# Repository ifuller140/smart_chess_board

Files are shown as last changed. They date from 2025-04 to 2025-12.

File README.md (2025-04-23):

# SmartChessBoard
Software Repository For Smart Chess Board Project

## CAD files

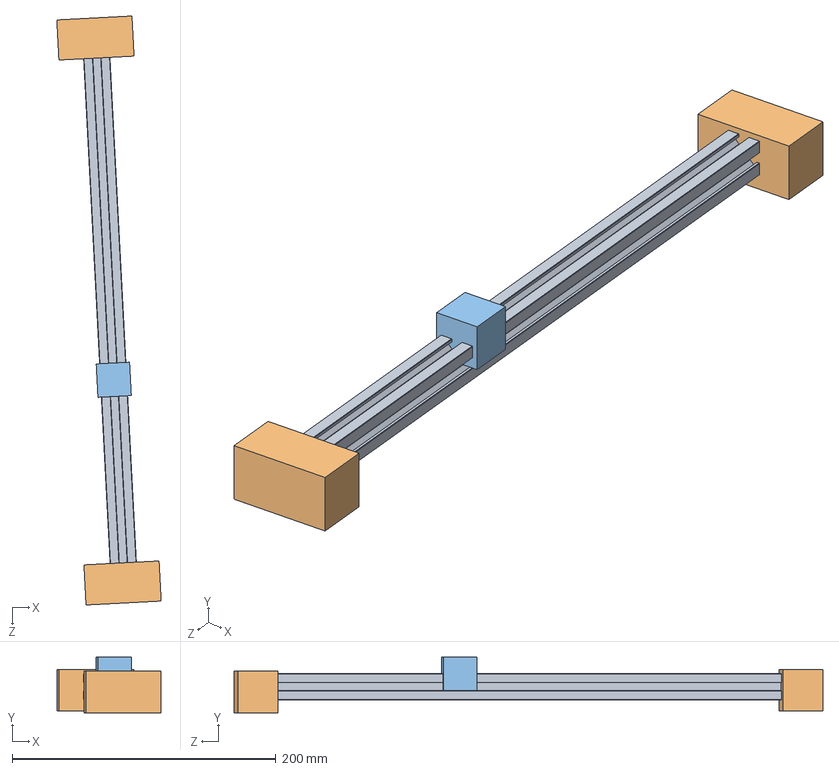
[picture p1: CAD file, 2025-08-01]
simulation/cad/exported files/Robot_Assembly.STEP
79.2 x 42.2 x 446.9 mm
Gantry_Bracket x 2
Gantry_Servo

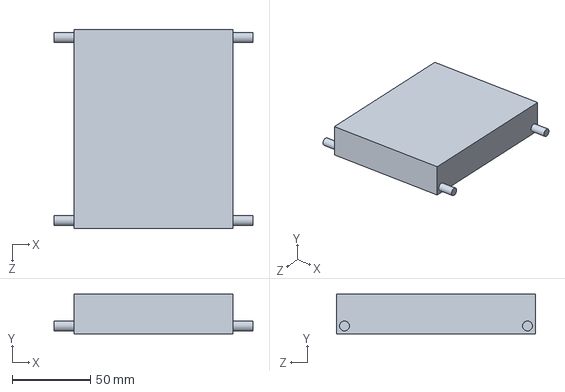
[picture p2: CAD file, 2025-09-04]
simulation/cad/Test/Main Frame.SLDPRT
127.0 x 25.4 x 127.0 mm

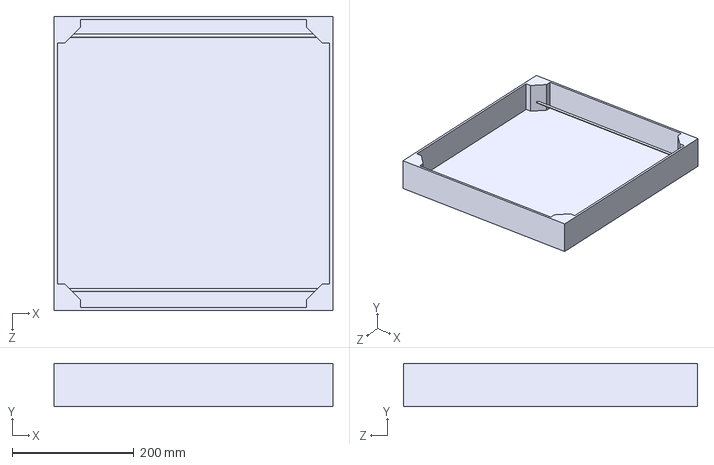
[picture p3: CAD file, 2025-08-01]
simulation/cad/exported files/Base_Assembly.STEP
457.2 x 71.1 x 482.6 mm

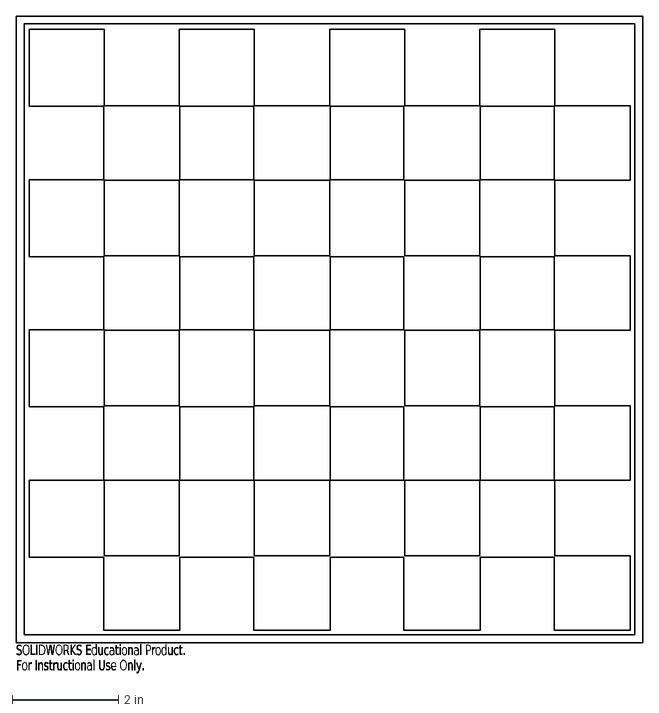
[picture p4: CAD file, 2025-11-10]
cad/exports/DXF/chess1.DXF
SOLIDWORKS Educational Product.
For Instructional Use Only.

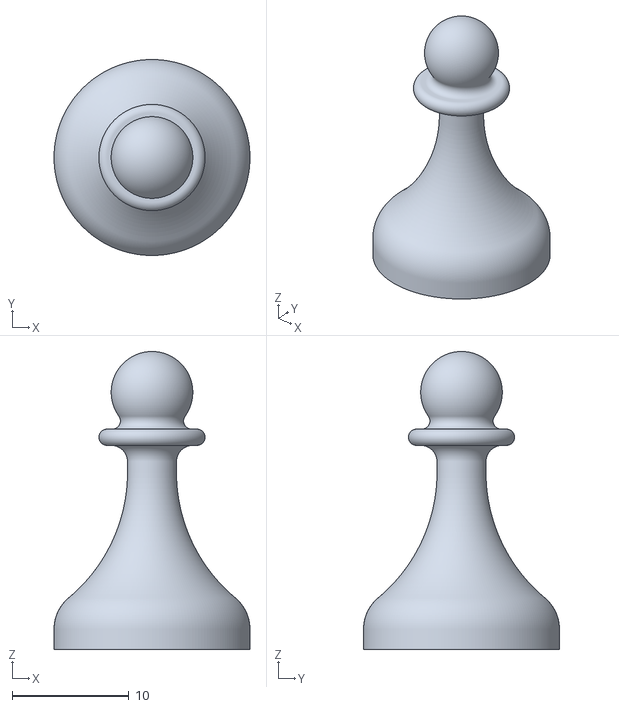
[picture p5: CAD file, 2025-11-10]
cad/exports/STLs/pawn.STL
16.8 x 16.8 x 25.5

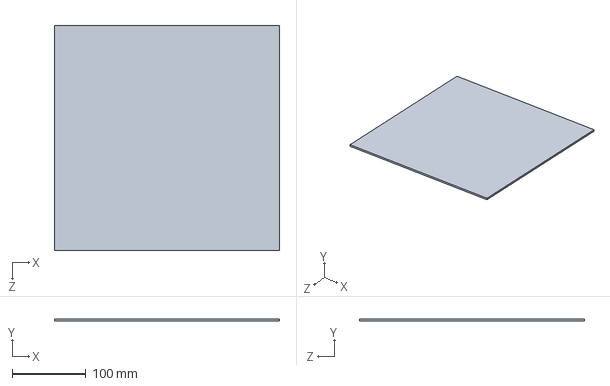
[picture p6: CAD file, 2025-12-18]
cad/parts/Chess Board.SLDPRT
304.8 x 3.17 x 304.8 mm

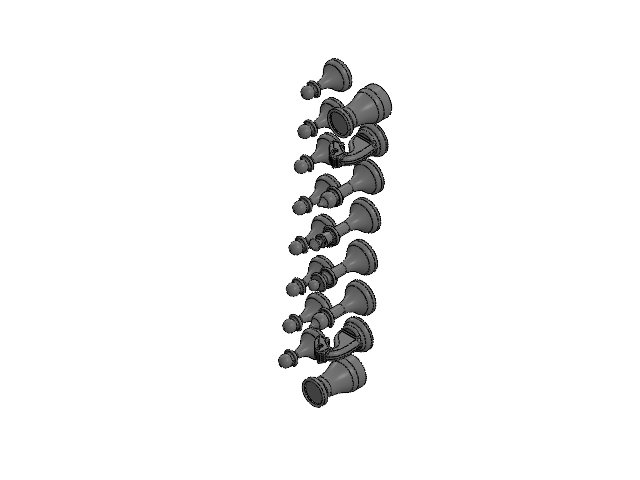
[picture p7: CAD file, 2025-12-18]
cad/parts/chess pieces/chess_pieces_assembly.SLDASM
bishop x 2
horse x 2
king
kings_crown
pawn x 8
queen
queens_crown
rook x 2

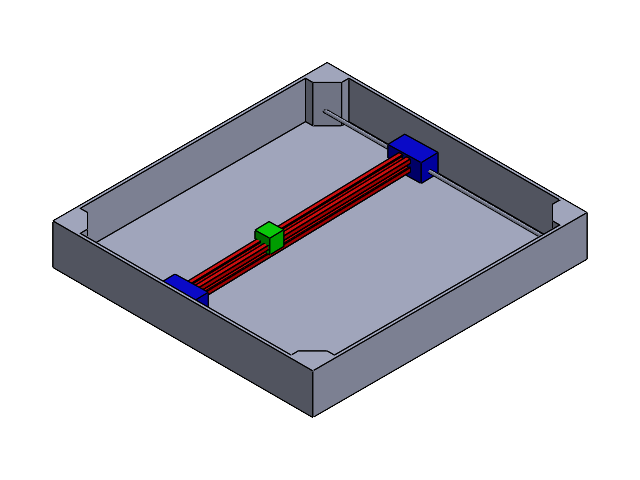
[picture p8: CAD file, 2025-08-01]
simulation/cad/assemblies/Full_Assembly.SLDASM
Gantry_Bracket x 2
Gantry_Servo
base

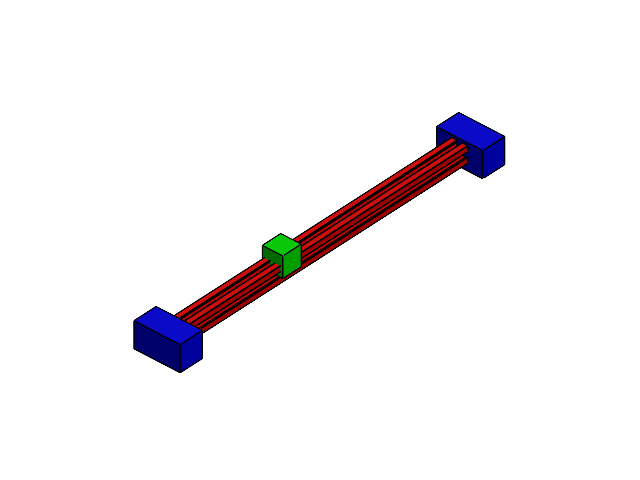
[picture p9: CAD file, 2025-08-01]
simulation/cad/assemblies/Robot_Assembly.SLDASM
Gantry_Bracket x 2
Gantry_Servo

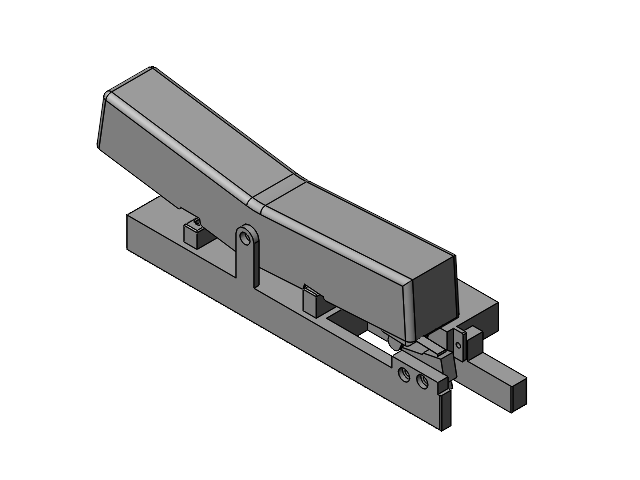
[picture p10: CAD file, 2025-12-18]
cad/parts/Inner Clock Subassembly.SLDASM
Servo base
servo rotator
Clock toy
Clock toy bottom
mini limit switch

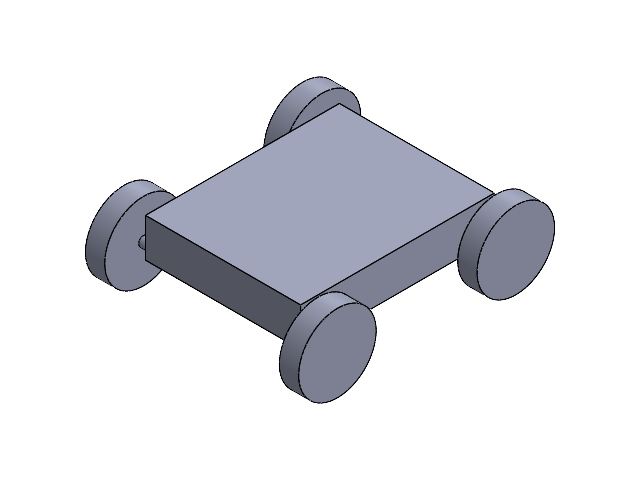
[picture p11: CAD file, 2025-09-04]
simulation/cad/Test/Assem1.SLDASM
Main Frame
Wheel x 4

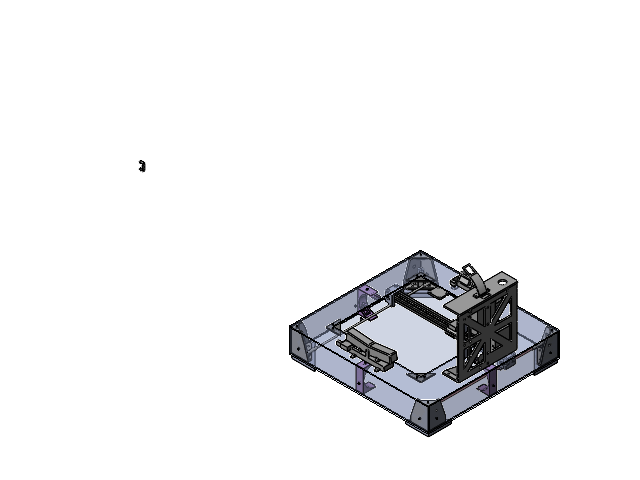
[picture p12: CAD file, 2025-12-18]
cad/parts/Assembly V2.SLDASM
Bottom V1
Side 19in x 2
Side 18in x 2
Vertical rod V1 x 2
bottom-side-top connector x 4
Top
Triangle piece holder x 4
Servo base x 2
servo rotator x 2
Clock toy
Clock toy bottom
mini limit switch x 3
clock face x 2
clock face holder
Battery
Raspberry Pi
Motor controller
Electronics peg board v2
Electronics top v2
Camera holder
Power Splitter x 2
Corner SW 1 x 2
Corner SW 2 motor
Stepper motor x 2
Rail rider
Servo magnet holder
feet V3 x 4
Tbone
Gates_2GT_20T_Toothed_Pulley x 4
Gates_2GT_20T_Toothed_Idler x 4
Corner SW 2 motor controller
Tbone clip
Wire holders under clcok housing x 2
Tbone without limit switches

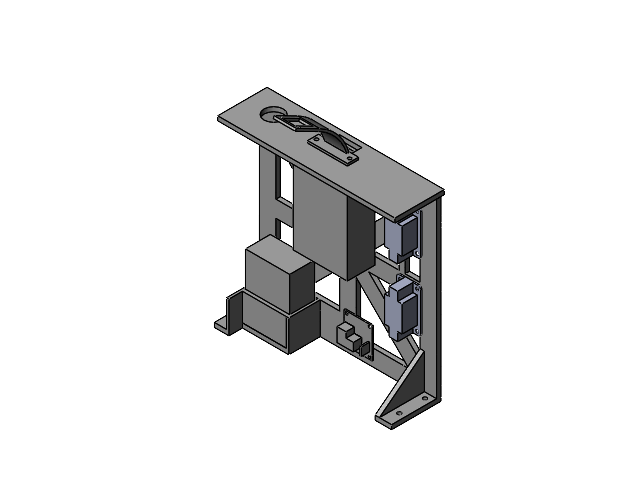
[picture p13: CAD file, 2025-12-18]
cad/parts/Electronics Assembly.SLDASM
Battery
Raspberry Pi
Motor controller
Electronics peg board v2
Electronics top v2
Camera holder
Power Splitter x 2

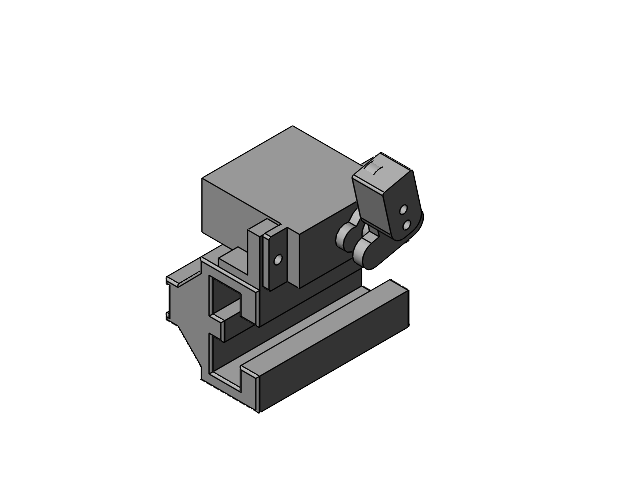
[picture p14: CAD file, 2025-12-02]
cad/parts/magent piece.SLDASM
Rail rider
Servo base
servo rotator
Servo magnet holder

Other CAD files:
simulation/cad/assemblies/Base_Assembly.SLDASM
cad/versions/Out of date/Assembly V1.SLDASM
cad/parts/Clock subassembly.SLDASM
cad/parts/Tbone assembly.SLDASM
cad/exports/Engineering drawings/Bottom V1.SLDDRW
cad/exports/Engineering drawings/Side 18in.SLDDRW
cad/exports/Engineering drawings/Side 19in.SLDDRW
cad/exports/Engineering drawings/Top.SLDDRW
cad/exports/STLs/Camera holder.STL
cad/exports/STLs/Clock toy bottom.STL
cad/exports/STLs/Clock toy.STL
cad/exports/STLs/Corner SW 1.STL
cad/exports/STLs/Corner SW 2 motor controller.STL
cad/exports/STLs/Corner SW 2 motor.STL
cad/exports/STLs/Corner2v2.stl
cad/exports/STLs/Corner2v3.stl
cad/exports/STLs/Electronics peg board v2.STL
cad/exports/STLs/Electronics peg board.STL
cad/exports/STLs/Electronics top v2.STL
cad/exports/STLs/Electronics top.STL
cad/exports/STLs/Feet.stl
cad/exports/STLs/Rail rider.STL
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

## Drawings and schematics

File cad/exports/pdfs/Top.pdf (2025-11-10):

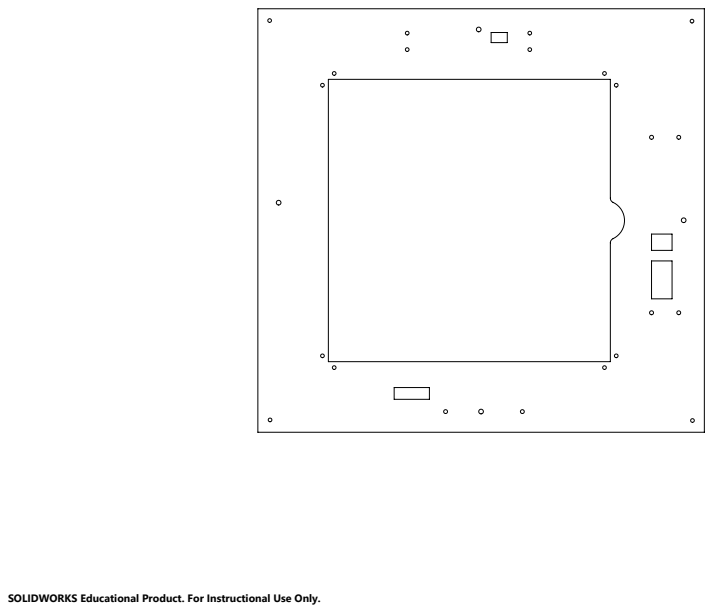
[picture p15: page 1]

SOLIDWORKS Educational Product. For Instructional Use Only.

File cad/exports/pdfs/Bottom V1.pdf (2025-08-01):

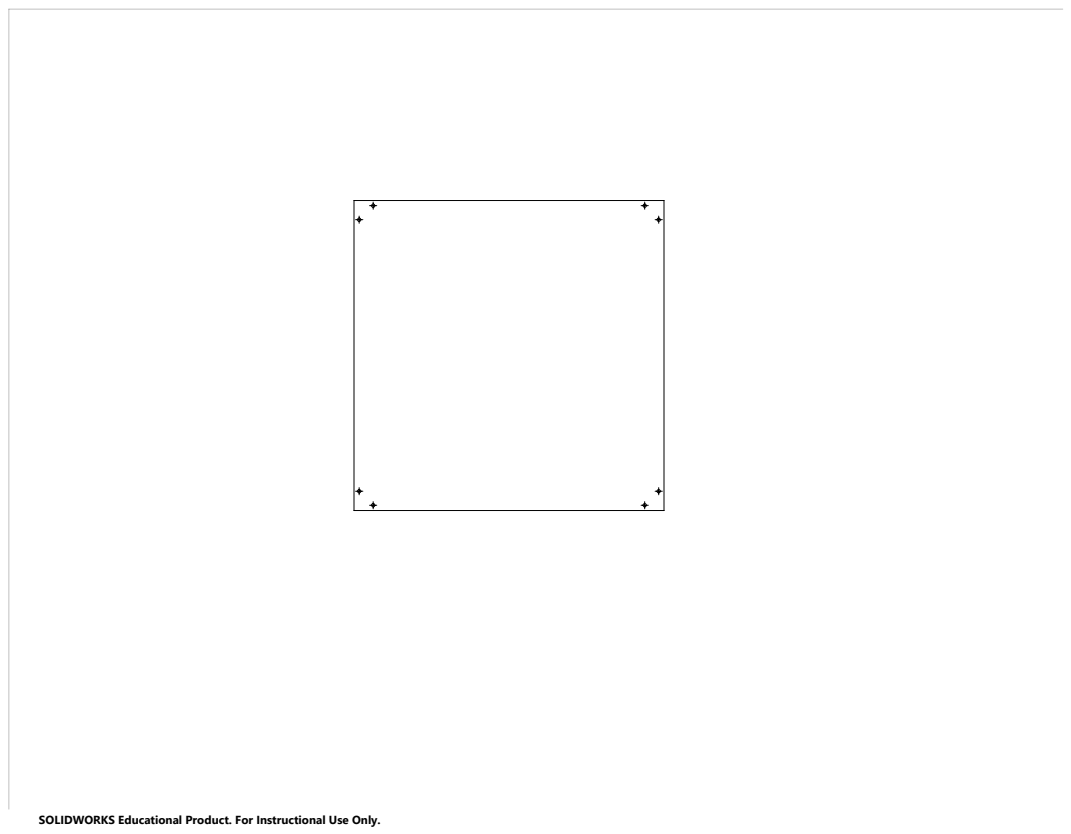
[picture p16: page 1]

SOLIDWORKS Educational Product. For Instructional Use Only.

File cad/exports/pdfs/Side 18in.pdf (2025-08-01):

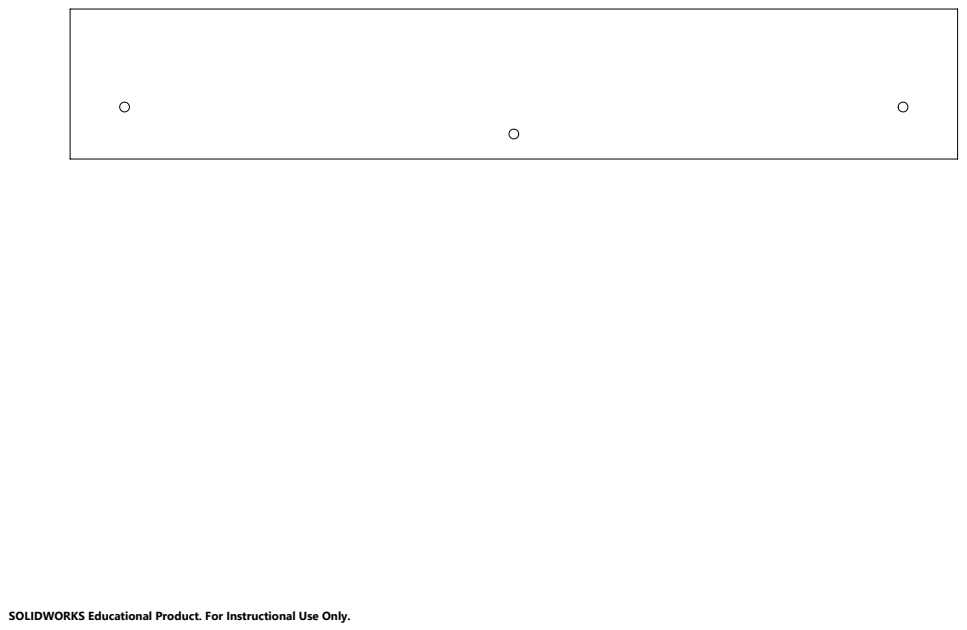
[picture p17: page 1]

SOLIDWORKS Educational Product. For Instructional Use Only.

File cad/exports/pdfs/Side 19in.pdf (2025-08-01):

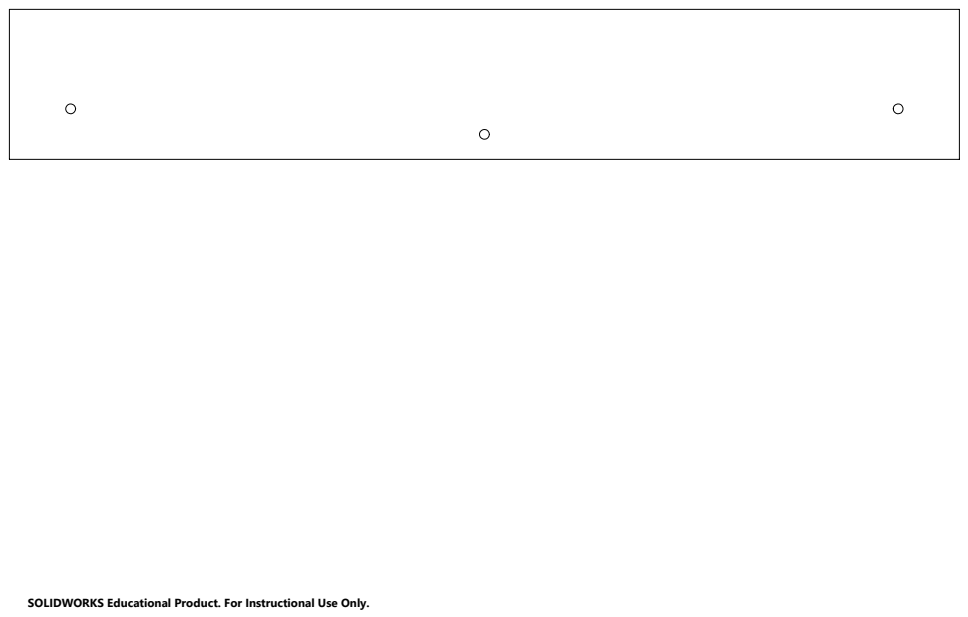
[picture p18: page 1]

SOLIDWORKS Educational Product. For Instructional Use Only.

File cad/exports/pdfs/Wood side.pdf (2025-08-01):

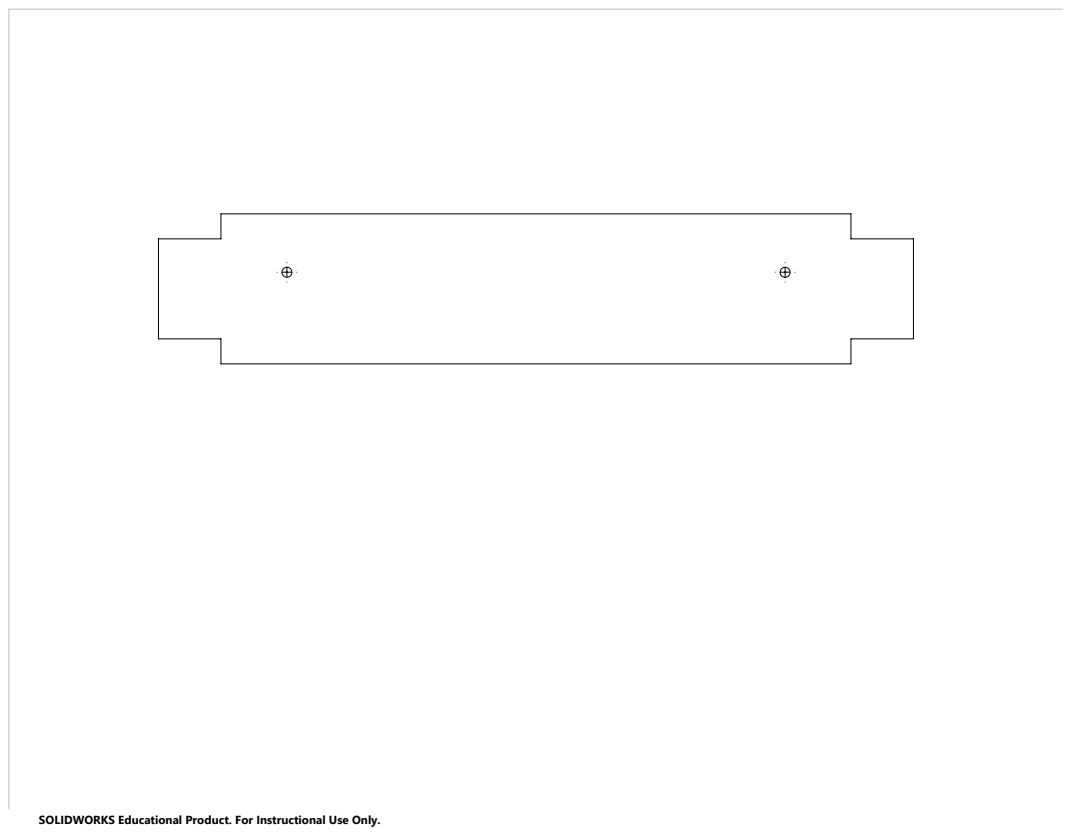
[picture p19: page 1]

SOLIDWORKS Educational Product. For Instructional Use Only.

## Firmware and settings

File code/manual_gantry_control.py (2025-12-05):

#!/usr/bin/env python3
import RPi.GPIO as GPIO
import time
import keyboard  # pip install keyboard

# ==========================
# GPIO PIN DEFINITIONS
# ==========================
# Motor A
IN1_A = 2
IN2_A = 3
IN3_A = 4
IN4_A = 14

# Motor B
IN1_B = 24
IN2_B = 23
IN3_B = 22
IN4_B = 27

# Define GPIO pins in arrays
motorA_pins = [IN1_A, IN2_A, IN3_A, IN4_A]
motorB_pins = [IN1_B, IN2_B, IN3_B, IN4_B]

# ==========================
# STEPPER SEQUENCE (28BYJ-48)
# ==========================
seq = [
    [1,1,0,0],
    [0,1,1,0],
    [0,0,1,1],
    [1,0,0,1]
]

# ==========================
# GPIO SETUP
# ==========================
GPIO.setmode(GPIO.BCM)
for pin in motorA_pins + motorB_pins:
    GPIO.setup(pin, GPIO.OUT)
    GPIO.output(pin, 0)

# ==========================
# STEPPER CONTROL FUNCTIONS
# ==========================
def step_motor(pins, direction=1, delay=0.002):
    """Step a single motor one cycle in the given direction."""
    seq_len = len(seq)
    for step in range(seq_len):
        for pin in range(4):
            GPIO.output(pins[pin], seq[step][pin] if direction > 0 else seq[-step - 1][pin])
        time.sleep(delay)

def move_both(dirA, dirB, steps, delay=0.002):
    """Move both motors simultaneously."""
    for _ in range(steps):
        step_motor(motorA_pins, dirA, delay)
        step_motor(motorB_pins, dirB, delay)

# ==========================
# COREXY MOVEMENT FUNCTIONS
# ==========================
def move_x(steps, delay=0.002):
    """Move X-axis: both motors same direction."""
    direction = 1 if steps > 0 else -1
    move_both(direction, direction, abs(steps), delay)

def move_y(steps, delay=0.002):
    """Move Y-axis: motors opposite directions."""
    direction = 1 if steps > 0 else -1
    move_both(direction, -direction, abs(steps), delay)

# ==========================
# MAIN LOOP: KEYBOARD CONTROL
# ==========================
try:
    step_size = 20     # Number of steps per key press
    delay = 0.0015     # Step timing (lower = faster)

    print("Manual Gantry Control Active!")
    print("Use arrow keys to move. Press 'q' to quit.\n")

    while True:
        if keyboard.is_pressed('up'):
            print("Moving UP (Y+)")
            move_y(step_size, delay)

        elif keyboard.is_pressed('down'):
            print("Moving DOWN (Y-)")
            move_y(-step_size, delay)

        elif keyboard.is_pressed('left'):
            print("Moving LEFT (X-)")
            move_x(-step_size, delay)

        elif keyboard.is_pressed('right'):
            print("Moving RIGHT (X+)")
            move_x(step_size, delay)

        elif keyboard.is_pressed('q'):
            print("Exiting program...")
            break

        time.sleep(0.05)

except KeyboardInterrupt:
    print("\nStopped by user.")

finally:
    GPIO.cleanup()
    print("GPIO cleaned up.")

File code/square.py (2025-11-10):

#!/usr/bin/env python3
import RPi.GPIO as GPIO
import time

# ==========================
# GPIO PIN DEFINITIONS
# ==========================
# Motor A
IN1_A = 2
IN2_A = 3
IN3_A = 4
IN4_A = 14

# Motor B
IN1_B = 24
IN2_B = 23
IN3_B = 22
IN4_B = 27

# Define GPIO pins in arrays
motorA_pins = [IN1_A, IN2_A, IN3_A, IN4_A]
motorB_pins = [IN1_B, IN2_B, IN3_B, IN4_B]

# ==========================
# STEPPER SEQUENCE
# ==========================
# Full_step sequence for 28BYJ-48
seq = [
    [1,1,0,0],
    [0,1,1,0],
    [0,0,1,1],
    [1,0,0,1]
]

# ==========================
# GPIO SETUP
# ==========================
GPIO.setmode(GPIO.BCM)
for pin in motorA_pins + motorB_pins:
    GPIO.setup(pin, GPIO.OUT)
    GPIO.output(pin, 0)

# ==========================
# STEPPER MOTOR FUNCTION
# ==========================
def step_motor(pins, direction=1, delay=0.002):
    """Step a single motor one step in the given direction."""
    global seq
    seq_len = len(seq)
    for step in range(seq_len):
        for pin in range(4):
            GPIO.output(pins[pin], seq[step][pin] if direction > 0 else seq[-step - 1][pin])
        time.sleep(delay)

def move_both(dirA, dirB, steps, delay=0.002):
    """Move both motors simultaneously."""
    for _ in range(steps):
        step_motor(motorA_pins, dirA, delay)
        step_motor(motorB_pins, dirB, delay)

# ==========================
# COREXY MOTION FUNCTIONS
# ==========================
def move_x(distance_steps, delay=0.002):
    """Move along X axis (both motors same direction)."""
    move_both(1, 1, distance_steps, delay)

def move_y(distance_steps, delay=0.002):
    """Move along Y axis (motors opposite directions)."""
    move_both(1, -1, distance_steps, delay)

def move_diag_xy(distance_steps, delay=0.002):
    """Move along diagonal bottom-left to top-right (X+Y+)."""
    move_both(1, 0, distance_steps, delay)  # Adjust ratio if needed

def move_diag_yx(distance_steps, delay=0.002):
    """Move along diagonal top-left to bottom-right (X-Y+)."""
    move_both(1, -1, distance_steps, delay)

# ==========================
# MAIN PROGRAM
# ==========================
try:
    steps_per_side = 300  # Adjust for desired size
    delay = 0.002

    print("Starting CoreXY square pattern...")

    # Square movement
    move_x(steps_per_side, delay)
    move_y(steps_per_side, delay)
    move_x(-steps_per_side, delay)
    move_y(-steps_per_side, delay)

    print("Square complete. Drawing X pattern...")

    # X pattern (diagonals)
    move_both(1, -1, steps_per_side, delay)   # diagonal 1
    move_both(-1, 1, steps_per_side, delay)   # diagonal 2

    print("Pattern complete.")

except KeyboardInterrupt:
    print("Interrupted by user.")
finally:
    GPIO.cleanup()

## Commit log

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2025-11-02 fixed broken mates
    [Assembly V2.SLDASM]
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2025-11-03 tbone enlarge tolerances
    [Assembly V2.SLDASM, Tbone assembly.SLDASM, Tbone without limit switches.SLDPRT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]
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2026-02-02 Add interactive stepper motor test with TM1637 display and improve A4988 timing constants for stability.
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2026-02-08 Implement pigpio DMA for jitter-free stepper motor control and update limit switch and button logic to active HIGH.
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2026-02-10 Refactor gantry hardware tests to use ROS nodes for control and fix inverted stepper motor direction logic
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2026-05-01 Fix perception stack: 10 critical bugs, refactor board detector, add auto-reference capture
    P0 fixes (crash/correctness):
    - BUG-06: picamera2 RGB→BGR conversion in camera_node._read_frame()
    - BUG-03: Fix BoardState.corners assignment (build list, don't index fixed array)
    - BUG-01: Calibration format — switch calibration.py save/load from .npz to OpenCV YAML
    - BUG-10: Remove duplicate rclpy.ok() in camera_node and piece_detector_node
    P1 fixes (bad behavior):
    - BUG-05: Fix white-piece brightness formula (was relative*board_mean, now absolute 0-255)
    - BUG-04/12: Fix board_detection.py comments (H/V labels); lower Hough threshold 100→70,
    reduce line requirement 8→4 for reli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
2026-05-01 Fix camera_node for Ubuntu 22.04: add GStreamer fallback, clear libcamera install instructions
    - camera_node: Replace monolithic _init_camera with three separate backends:
    1. picamera2 (preferred) — now logs exact apt install command when libcamera missing
    2. GStreamer libcamerasrc pipeline (Ubuntu 22.04 fallback, works if OpenCV has GStreamer)
    3. OpenCV V4L2 — probes /dev/video0-3, validates frames are non-black before accepting
    - camera_node: Fix 'OpenCV capture read failed' spam — V4L2 fallback now test-reads
    before accepting the device, so if V4L2 cannot produce real frames it logs one clear
    error rather than flooding the console
    - install_libcamera_python.sh: Rewrite w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
2026-05-01 Switch perception launches to use ros-humble-camera-ros for Ubuntu 22.04 Pi
    On Ubuntu 22.04, python3-libcamera is not in standard repos and the RPi
    Foundation repo uses Debian naming (not Ubuntu). ros-humble-camera-ros IS
    available and works: camera detected as imx219, BGR888 format supported.
    Both launch files now default to use_camera_ros:=True which starts
    camera_ros camera_node with format=BGR888 remapped to /camera/image_raw.
    This produces proper bgr8 images so all downstream nodes work correctly.
    Old chess_perception camera_node is kept as fallback with:
    use_camera_ros:=False (+ optional use_picamera2:=True/False)
    New parameters exposed in both launch files:
    use_camera_ros (bool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
2026-05-01 Fix camera_ros topic remap: use fully-qualified path not relative
    camera_ros publishes to /camera_node/image_raw (fully qualified), not
    the relative 'image_raw'. Relative remaps are ignored. Use absolute
    path remap: /camera_node/image_raw -> /camera/image_raw.
2026-05-01 Add detection_scale and skip_frames to board_detector_node to fix CPU overload
    On Pi 4 at 12fps with 1280x720, board_detector_node was using 114% CPU
    (pegging a full core) because Hough line detection on a high-res frame
    is expensive.
    Fix: detect at half resolution (detection_scale=0.5, 640x360), then
    scale corners back up to 1280x720 coordinates. Also skip every other
    frame (skip_frames=2). Result: ~25% CPU, 3-6 detections/sec.
    Corners from the last successful detection are cached and re-published
    on skipped frames, so piece_detector_node sees continuous geometry.
2026-05-01 board_detector_node: run detection in background thread to fix 100%+ CPU
    Replaced skip_frames approach with a dedicated detection thread:
    - ROS image_callback stores latest frame and signals the thread (never blocks)
    - Detection thread runs at whatever rate the hardware allows (~3-6fps at 640x360)
    - Intermediate frames are dropped (latest always wins)
    - Published at: board_geometry always has corners, board_debug follows detection rate
    This keeps ROS executor responsive and CPU at ~25-35% instead of 100%+.
    Detection still runs at 0.5x scale (640x360 for 1280x720 input).
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2026-05-01 Lower camera to 640x480 and tune board_detector for manageable CPU load
    At 1280x720 + 12fps, numpy frame conversion alone consumed ~100% CPU in
    Python nodes. 640x480 is 4x fewer bytes per frame, reducing baseline CPU
    from ~100% to ~25% per node.
    - perception_launch.py: width/height defaults 1280x720 -> 640x480
    - perception_test_launch.py: hardcoded 1280x720 -> 640x480
    - board_detector_node: detection_scale 0.25 -> 0.5 (now 320x240 at 640x480)
    detection_interval_ms 200 -> 150ms (6fps detection)
    640x480 is still sufficient for board detection and piece color classification.
    The piece_detector warps to a fixed 400px square regardless of input size.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
2026-05-01 Fix 100%+ CPU: timer-driven detection, no-copy frame decode in both detector nodes
    Root cause: both nodes decoded every camera frame (12fps * 921KB = 11MB/s
    numpy copies) even when detection ran at a lower rate.
    board_detector_node:
    - _on_image now just stores raw msg reference (no numpy)
    - Timer at 5Hz decodes latest frame and runs detection
    - Drops threading approach in favor of timer (simpler, same result)
    piece_detector_node:
    - _on_image renamed _on_image_raw, stores raw msg only
    - New _detect_tick timer at 3Hz decodes + runs piece detection
    - Added detection_hz parameter (default 3.0)
    - np.array() replaced with np.frombuffer() + .copy() (no intermediate copy)
    Result: CPU drops from 1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
2026-05-01 Switch detector nodes from raw to JPEG compressed subscription (~30x less DDS overhead)
    Root cause of 100%+ CPU: DDS was deserializing 921KB raw image messages for
    EACH subscriber (board_detector + piece_detector = 22MB/s). JPEG compressed
    images from camera_ros are ~30KB, reducing IPC to <1MB/s.
    - board_detector_node: subscribe CompressedImage on /camera/image_raw/compressed
    decode with cv2.imdecode() (returns BGR, already correct)
    - piece_detector_node: same compressed subscription + decode
    - Both launch files: remap /camera_node/image_raw/compressed -> /camera/image_raw/compressed
    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
2026-05-01 Fix busy-loop spin in all perception nodes: use spin_once(timeout_sec=0.1)
    rclpy.spin() calls spin_once(timeout_sec=0) internally, which is a pure
    busy-loop (no sleep between events). With multiple subscriptions and timers,
    this consumed 90-110% CPU even when callbacks ran at 3-5Hz.
    Fix: use executor.spin_once(timeout_sec=0.1) which sleeps up to 100ms
    when idle. For 5Hz board_detector and 3Hz piece_detector, this reduces
    idle CPU from ~100% to <5%.
    Applied to: camera_node, board_detector_node, piece_detector_node.
2026-05-01 Add throttle node to limit camera to 5fps for detector nodes
    Camera publishes JPEG at ~28fps native sensor rate. Two DDS subscribers
    at 28fps creates ~17 background threads per Python process burning 100%+
    CPU even when callbacks are trivial.
    Add ros-humble-topic-tools throttle node that re-publishes:
    /camera/image_raw/compressed -> /camera/image_slow/compressed at 5fps
    board_detector_node and piece_detector_node remap to the 5fps topic.
    camera_ros raw topic at 28fps stays available for future consumers.
    Requires: sudo apt install ros-humble-topic-tools (already installed).
2026-05-01 Fix spin busy-loop: use spin_once(timeout_sec=0) + explicit sleep(5ms)
    spin_once(timeout_sec=0.1) does not reliably sleep on CycloneDDS/ARM Pi 4
    — the main thread ran at 98% CPU even with throttled 5fps subscription and
    5Hz detection timer. Per-thread top confirmed this was the main Python thread.
    Fix: spin_once(timeout_sec=0) + time.sleep(0.005) in the spin loop.
    This forces a 5ms idle sleep between callback checks. At 5Hz timer (200ms
    period), the timer fires within 5ms of being due. Expected CPU: ~10-15%
    for board_detector (5fps * 25ms detection) + negligible loop overhead.
    Applied to board_detector_node and piece_detector_node.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
2026-05-01 Reduce detection rates: board_detector 0.25x scale 2Hz, piece_detector 2Hz
    Profiling on Pi 4B showed BoardDetector.detect() takes 322ms at 320x240
    (0.5x scale of 640x480). At 5Hz that's 1611% CPU — impossible.
    Root: findContours fallback on non-board images is slow (~250ms at 320x240).
    Fix:
    - board_detector: scale 0.5->0.25 (160x120, ~40ms/detect), hz 5.0->2.0
    Expected: 2 * 40ms = 80ms/sec = ~8% CPU for detection
    - piece_detector: hz 3.0->2.0 (square analysis is lighter but camera at 5fps
    anyway, so 2Hz is fine for game state tracking)
    2fps detection is sufficient for chess piece tracking — pieces don't move
    faster than 1-2 seconds per move.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
2026-05-01 Switch to spin_once(timeout_sec=None) for proper blocking wait
    Earlier attempts showed timeout_sec=0.1 burned 98% CPU, suggesting
    something always wakes the wait set early. Try timeout_sec=None which
    blocks until the next actual event (subscription/timer), eliminating
    all sleep overhead. CPU should approach 0% when idle, only active
    during actual callback execution.
    If this still shows high CPU, the cause is inside the detection callbacks
    themselves, not the spin mechanism.
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2026-05-01 Fixed camera focused field of view, added more camera lense distortion corrections in fen_visualizer
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2026-07-08 chess_os: remove duplicated local vision/FEN pipeline
    Step 1 of the Chess OS architecture consolidation initiative. Deletes
    chess_os.py's own blob-detection piece finder, FEN builder, warp/
    undistort math, and manual corner-drag calibration UI — all of which
    duplicated logic that board_detector_node and piece_detector_node
    already do correctly and automatically. chess_os now only displays
    their ROS output (/api/diff_frame, /api/square_scores) plus the raw
    camera feed, and reads FEN solely from /game_manager/board_fen.
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2026-07-08 chess_os: fix capture_reference reporting success on service failure
    Found live on the Pi while verifying Step 1: api_capture_reference
    only checked whether _call_svc's return was a tuple (the ROS-not-
    connected case) and otherwise assumed success, ignoring the actual
    `ok` field from the /perception/capture_premove service response. A
    failed capture (e.g. board_detector_node hasn't found a board yet)
    was silently reported as "Reference captured (checkmark)" in the UI.
2026-07-08 chess_os: push board calibration to motion_planner_node live
    Step 2 of the Chess OS architecture consolidation initiative,
    adjusted from the original plan: the plan assumed square_to_mm()
    could be deleted in favor of resolving squares through the MoveGantry
    action, but MoveGantry's goal is XY millimeters, not square names —
    there's no ROS-native way to resolve a square without computing mm
    somewhere, and chess_os's manual Square Nav debug tool has no other
    way to do it. Deleting square_to_mm() would have broken that tool
    with no replacement.
    The real duplication risk was silent divergence: calibrating via the
    Chess OS UI (save a1/h8, apply) only ever updated chess_os's own
    local board_cal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
2026-07-08 docs: update all current-reference docs for chess_ui cutover
    Was accidentally left out of the previous commit (git add errored
    silently on the already-deleted code/chess_os.py pathspec, which aborted
    staging of every other path in that command).
    Updates README.md, CLAUDE.md, docs/CONTEXT.md, docs/software/nodes.md,
    docs/software/architecture.md, docs/features/README.md from
    `python3 code/chess_os.py` to `ros2 run chess_ui chess_ui`, refreshes the
    Perception/Tests tab descriptions to match current behavior, and records
    Step 4's live Pi verification plus the recurring camera_ros stale-
    subscriber bug in .agent/PROJECT_STATUS.md and docs/CHANGELOG.md.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
2026-07-08 Delete superseded code/ scripts (Step 5, final step of Chess OS initiative)
    gantry_calibration.py, hardware_test.py, calibration_verify.py, square.py:
    all duplicate ROS-side homing/motion-planning/testing logic with hardcoded
    GPIO pins that could silently drift out of sync with pins.yaml. Verified
    each one's ROS-side equivalent exists and works (gantry_control package,
    chess_hw_interface test suite via test_runner_node) before deleting, and
    confirmed via git grep that nothing else references them.
    Also deleted ServoTestController.py, which the plan hadn't originally
    flagged: turned out to be unrelated dead code from the pre-NEMA11/A4988
    hardware iteration (a 28BYJ-48/ULN2003 half-step stepp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
    [ServoTestController.py, square.py]
2026-07-08 Fix gantry coordinate-system config mismatch (Phase 1 of audit remediation)
    board_map.yaml documented the old bottom-right-origin convention while
    motion_planner_node.py actually implements bottom-left-origin — 5 of 8
    files (d-h) were unreachable, rejecting moves like e2e4. Rewrote the yaml
    to match the code's own already-correct defaults, fixed the
    board_edge_safe_x_mm param name (yaml had board_edge_left/right_x_mm,
    which ROS silently ignored), and reconciled the 3-way x_max_mm mismatch
    between homing_node (240 default), gantry_kinematics_node/yaml (250),
    and gantry_kinematics_node.py's own stray fallback (300) down to a
    single consistent 250mm placeholder pending physical measurement.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
2026-07-08 docs: record Phase 1 completion and live-verification results
    PROJECT_STATUS.md and IMPLEMENTATION_PLAN.md updated with Phase 1's
    live-verification results on the Pi (ros2 param get confirming the
    corrected coordinate values) and the caveat that homing_node's param
    wasn't live-verified since pigpiod isn't running non-interactively.
2026-07-08 Fix game_manager_node permanent game-loop death (Phase 2 of audit remediation)
    Homing failure and every game-end path (checkmate/stalemate/draw/flag-fall/
    resignation/no-legal-moves) previously broke or returned out of the
    daemon game-loop thread, killing it permanently — /game/start,
    /game/new_game, and /game/resign stayed registered and kept reporting
    success=True while doing nothing, since nothing was left running to
    service them. Confirmed live on the Pi during the 2026-07-08 audit.
    Fixes:
    - Homing failure now retries automatically every 5s (HOMING_FAILED
    state) instead of returning from the thread.
    - Every game-end path now falls through to a paused wait for
    /game/new_game (_PAUS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
2026-07-09 docs: record Phase 2 completion and live-verification results
    Documented the full Phase 2 verification session: homing-retry cycling
    confirmed alive for 35+s with no /gantry/home available, a complete
    synthetic turn cycle, the exact audit-reproduced resign->new_game bug
    now confirmed fixed, MOTION_ERROR path verified not to desync the
    board model, and the awaiting-gate stale-event fix confirmed rejecting
    late callbacks.
2026-07-09 Phase 3: fix blocking executors defeating e-stop, action double-terminal-state bug, hw-test cancel/GPIO interlock
    Every hardware node (homing_node, stepper_driver_node, servo_node,
    clock_servo_node, gantry_kinematics_node) ran a default single-threaded
    executor with a blocking service/action callback, so /emergency_stop could
    never be processed mid-motion — and for gantry_kinematics_node specifically,
    its own /gantry/pose feedback subscription also couldn't fire while its
    action callback blocked, meaning a move could never detect arrival at all.
    Switch each to MultiThreadedExecutor with the blocking work and
    /emergency_stop (and, for gantry_kinematics_node, pose/limit subscriptions)
    in sep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
2026-07-09 fix: forward cancel_check through hardware test subclass constructors
    Several HardwareTest subclasses (GantryTestBase, VisionDetailBase, and 5
    others) override __init__(gpio_interface, display_interface) without
    **kwargs and call super().__init__() with only those two positional args,
    so the new cancel_check param from the test-runner killswitch fix wasn't
    reaching them — instantiating any of these (GantryFullTest, BoardCalibrationTest,
    CameraCornerDetectionTest, etc.) via run_test() raised
    TypeError: unexpected keyword argument 'cancel_check', which run_all --mock
    --all caught on the very first test. Found by actually exercising the
    killswitch mid-suite rather than trusting a read-through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
2026-07-09 Phase 5+6: fix chess_perception and chess_ui audit findings
    chess_perception (Phase 5):
    - camera_node: fallback backend now publishes /camera/image_raw/compressed
    (CompressedImage) — board_detector_node/piece_detector_node only ever
    subscribed to the compressed topic, so this backend previously fed
    perception zero frames silently.
    - piece_detector_node: premove_avg_count now does real multi-frame
    averaging via non-blocking timer-driven accumulation (was dead code —
    every call captured exactly one frame regardless of the setting).
    - board_detection.py/board_detector_node: corner TL/TR/BR/BL labeling now
    anchors to the previous detection via nearest-neighbor match instead of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
2026-07-09 fix: pin camera_ros to full-FOV sensor mode, fixing severely cropped board view
    camera_ros's sensor_mode was never set at launch, so libcamera's own mode-
    selection heuristic picked a raw sensor mode independently of the requested
    width/height -- for this sensor+role+size combination it silently chose a
    dead-centered ~39%x39% crop of the full 3280x2464 array (confirmed via
    `ros2 param get /camera_node ScalerCrop` defaulting to {(1000,752)/1280x960}),
    meaning only the center ~4 squares of the board were ever in frame, no matter
    how the physical camera was aimed.
    Pinning sensor_mode to the sensor's native 2x2-binned full-FOV raw mode
    (1640x1232) forces the ISP to crop the full array before sc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
2026-07-09 docs: record camera-framing root cause/fix and the missing corner-UI gap
    Documents the camera_ros sensor_mode bug found and fixed this session, plus
    a new finding surfaced while investigating it: the manual corner-drag UI was
    deliberately removed during the Chess OS consolidation on the assumption
    that automatic detection made it redundant -- an assumption that didn't
    hold because the camera bug had silently broken automatic detection the
    whole time. There is currently no way to see or override what the automatic
    detector finds. Not yet scoped as an implementation phase.
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2026-07-09 docs: record Phase 8a live verification (camera exposure/AWB lock)
    Clean before/after on the same untouched board: unlocked mean diff score
    27.7 with 33/64 squares falsely above the default 18.0 threshold; locked
    mean 4.85 with 0/64 above threshold. Also documents the design adjustment
    made during implementation (toggle Ae/AwbEnable off rather than sample-
    then-pin specific values, since camera_ros can't read back AE-computed
    values and ExposureTime's parameter range is separately broken).
2026-07-09 Phase 8b: stability-gated post-move capture (vision robustness)
    piece_detector_node publishes a changed-squares reading on every detection
    tick (~0.5s), not once per capture. game_manager_node's _do_capture_board()
    previously accepted whatever the very first tick reported after the clock
    press -- which could catch a hand still over the board, mid-motion blur, or
    a camera-settling frame. Now waits for capture_stability_count (default 3)
    consecutive identical readings before trusting the result, falling back to
    the most-common (mode) reading if board_capture_timeout_s (now 10.0, up
    from 5.0 to give the stability wait room) elapses without one fully
    stabilizing -- same timeout-with-fallback pat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
2026-07-09 Phase 8c: perspective-aware ROI bias + edge/structure diff channel
    A piece is a physical object with height, so it doesn't sit flush with the
    board plane the homography is computed for -- only its board-contact point
    projects correctly through the warp; the rest of its silhouette "leans" in
    the warped image, worse for ranks farther from the camera. Adds
    roi_bias_fraction to piece_detector_node: shifts each square's sampled
    vertical window (not its size) toward whichever edge actually carries the
    reliable signal. Direction/magnitude is a physical-camera-geometry fact,
    so it's a signed, tunable parameter (default 0.0, unchanged behavior)
    rather than a hardcoded guess -- the debug image now dra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
2026-07-09 Phase 8d: confidence-scored legal-move matching (vision robustness)
    _match_legal_move() previously worked off the boolean-thresholded
    changed-squares set, exact-matching a legal move's footprint and, on
    failure, trying to drop exactly one extra square as noise tolerance. That
    can handle either a missed detection OR a false positive, but not both at
    once, and doesn't use the continuous diff scores piece_detector_node
    already publishes.
    Replaces it with _move_match_score(): for every legal move, sum the scores
    on its footprint squares minus every OTHER square still elevated above
    match_noise_floor and left unexplained. The highest-scoring legal move
    overall wins -- naturally tolerant of misse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
2026-07-09 Phase 8e: corner-overlay visibility + manual corner-drag override
    board_detector_node already published an annotated corner-detection debug
    image (/perception/board_debug) that chess_ui never displayed anywhere --
    there was no way to see what the automatic detector found, correct or not.
    Now shown live in the Perception tab.
    Also restores a manual corner-override, removed during the 2026-07-08
    Chess OS consolidation on the premise that automatic detection made it
    redundant -- a premise broken by the camera-framing bug fixed earlier this
    session (automatic detection had been silently broken by it the whole
    time, with no fallback). board_detector_node now subscribes to
    /perception/manual_corn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
2026-07-09 docs: record Phase 7/8e live verification, close out Phase 8 initiative
    Confirmed the manual corner override works both directions (apply/clear)
    against the real production board_detector_node, and caught a real live
    bug in the process: automatic detection sometimes locks onto an internal
    sub-rectangle instead of the true board boundary, visible for the first
    time via the new corner-overlay this phase adds. Demonstrated the manual
    override fixing it in real time. Turn-by-turn tuning log deferred as lower
    priority. Also fixes the phase-status summary table at the top of
    IMPLEMENTATION_PLAN.md, which had drifted out of sync with the detailed
    per-phase sections below it as work landed through t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
2026-07-09 fix: chessboard.js piece images 404'd — wrong CDN path had no image assets
    pieceTheme pointed at unpkg's @chrisoakman/chessboardjs@1.0.0 tarball, which
    only ships dist/{js,css} — no img/ directory — so every piece image request
    404'd, showing as flickering broken-image icons on every ~500ms status poll.
    Switched to chessboardjs.com's own canonical asset host (confirmed reachable
    from both here and the Pi).
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
